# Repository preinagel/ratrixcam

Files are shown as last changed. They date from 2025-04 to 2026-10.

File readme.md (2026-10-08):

## Overview
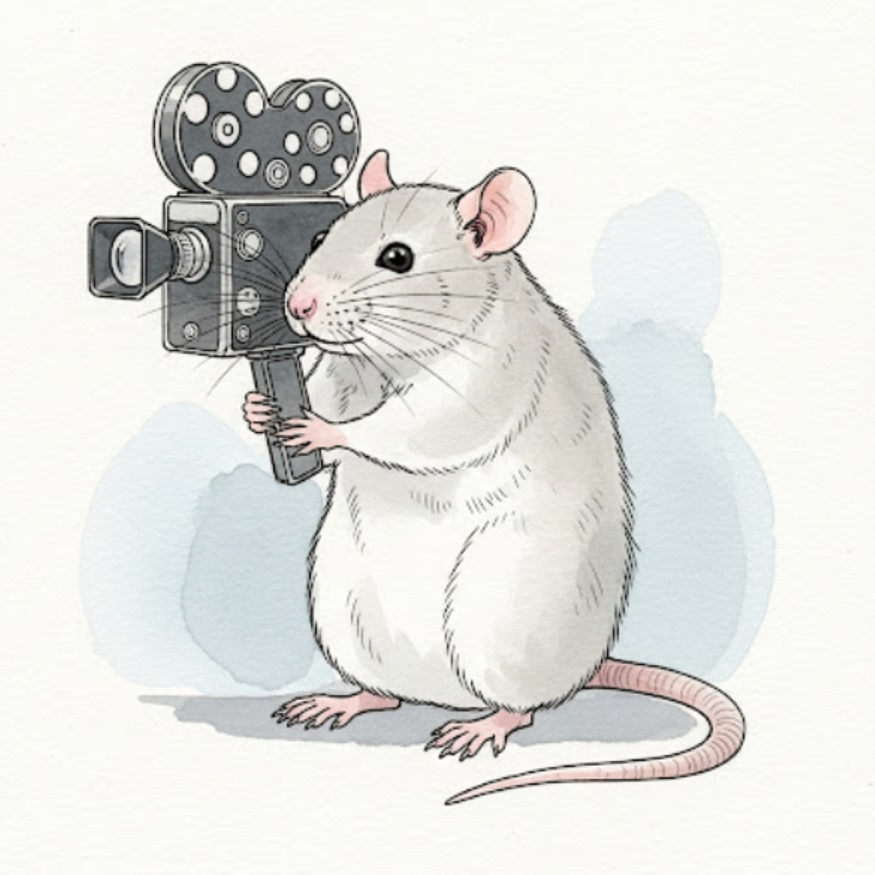
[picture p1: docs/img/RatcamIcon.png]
 The ratrixCam system is an inexpensive, bare-bones open-source hardware and software package designed to record video 24 hours a day 7 days a week for at least 1 week continuously, with the minimum possible frame drops within videos or gaps between videos. It was developed for in-home-cage animal behavior monitoring, but could be used in any application requiring continuous uninterrupted video recording. The code provides a minimal graphical user interface that allows the user to monitor the camera status and session statistics during the run. The code is currently verified to support up to 8 cameras streaming at 30fps, 640x480p. 

See the [Camera User Manual](./docs/CameraUserManual.md), the [VideoProc User Manual](./docs/VideoProcUserManual.md) and [Setup Instructions](./docs/SetUpInstructions.md) for more information.

Project started by Blake Bruell and Pamela Reinagel 2025

With support from the [NIH BRAIN Initiative](https://braininitiative.nih.gov/) and [NINDS](https://www.ninds.nih.gov/) 1R34NS132037-01

## Running the tests

The `videoproc` tools (`compress_drive.py`, `confirm_and_delete.py`) have a pytest suite
under `tests/`. It generates its own synthetic video clips and runs entirely in temporary
directories -- no real recordings or network drives are touched.

Requirements: Python 3.10+, `ffmpeg` on PATH, and the packages `videoproc` itself already
needs (`opencv-python`, `numpy`), plus `pytest`:

    pip install -r requirements-dev.txt

Run the suite from the repository root:

    pytest -v

GitHub Actions runs the same suite on every push and pull request to `dev` and `main`
(see `.github/workflows/tests.yml`).

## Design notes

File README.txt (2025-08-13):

ratrixCam 0.0

The ratrixCam system is an inexpensive, bare-bones open-source hardware and software package designed to record video 24 hours a day 7 days a week for at least 1 week continuously, with the minimum possible frame drops within videos or gaps between videos. It is currently verified to support up to 8 cameras streaming at 30fps, 640x480p. It relies on MacMini hardware, ArduCam USB cameras, high-end USB Hubs, and high-speed, high-capacity external SSD drives. The code provides a minimal graphical user interface that allows the user to monitor the camera status and session statistics continuously during the run.

Project started by Blake Bruell and Pamela Reinagel 2025

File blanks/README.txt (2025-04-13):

Blank images to display when camera is offline

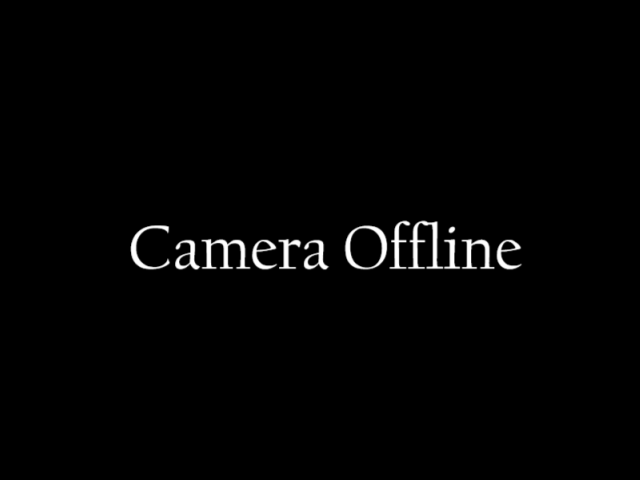
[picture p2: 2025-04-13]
blanks/offline_status.png

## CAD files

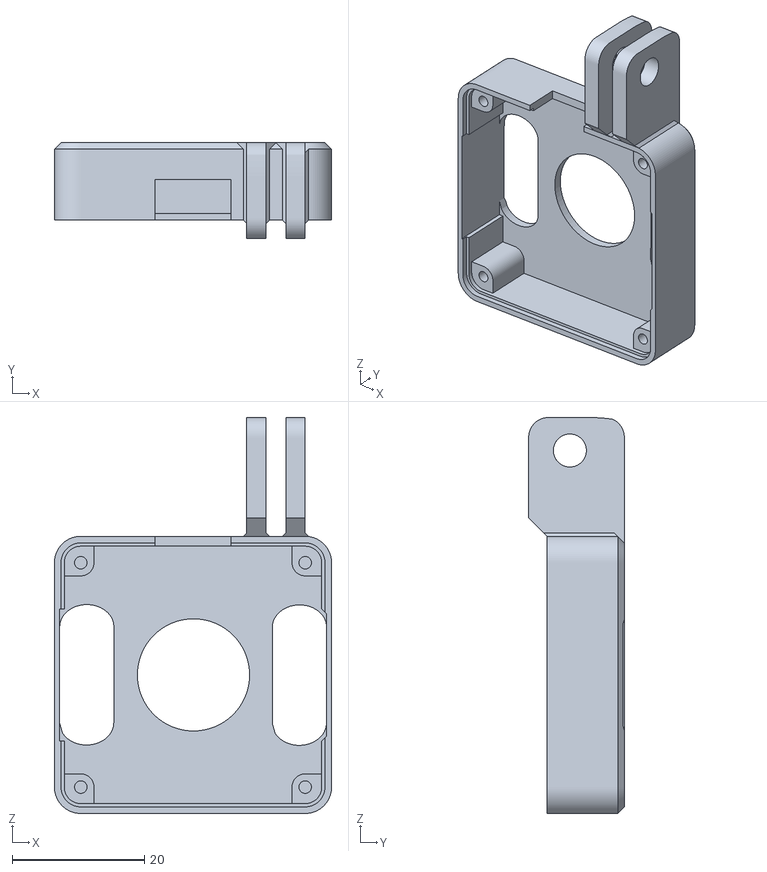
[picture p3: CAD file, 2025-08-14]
docs/ratrixCamCameraCaseFront.stl
42.0 x 14.5 x 60.0

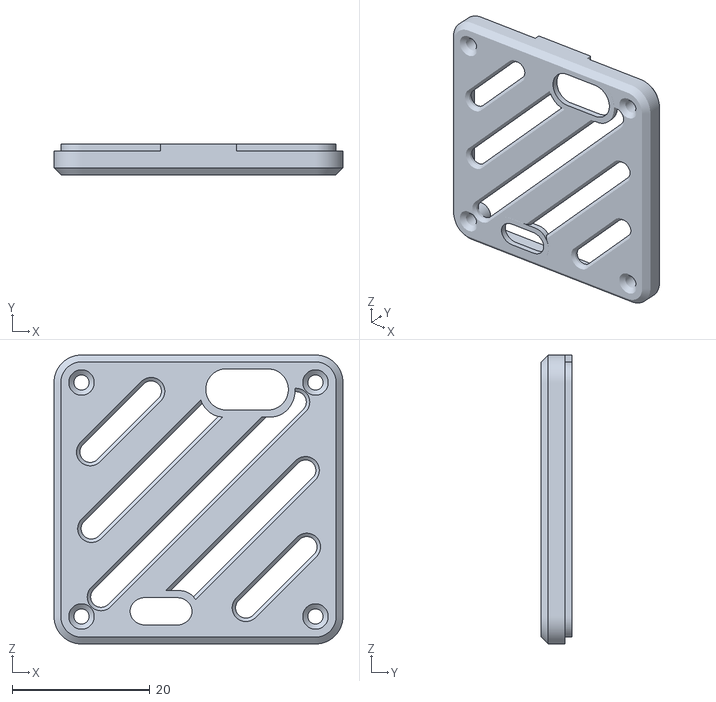
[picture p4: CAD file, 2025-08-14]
docs/ratrixCamCameraCaseBack.stl
42.0 x 4.54 x 42.0

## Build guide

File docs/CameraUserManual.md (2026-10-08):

## Overview
 The ratrixCam system is an inexpensive, bare-bones open-source hardware and software package designed to record video 24 hours a day 7 days a week for at least 1 week continuously, with the minimum possible frame drops within videos or gaps between videos. It was developed for in-home-cage animal behavior monitoring, but could be used in any application requiring continuous uninterrupted video recording. The code provides a minimal graphical user interface that allows the user to monitor the camera status and session statistics during the run. The code is currently verified to support up to 8 cameras streaming at 30fps, 640x480p. 

### System Operation in Brief
- Attach an empty SSD drive
- Launch software
- Click "Start Recording" 
  (Camera images will be displayed while recording) 
- Every week or so:
  - Click "Stop Recording"
  - Swap out full SSD drive for empty one
  - Click "Start recording"
  - Transfer videos off the full SSD drive

## Operation Instructions in Detail
Double click on `cam_start.scpt` to open it, and click ‘play’ to launch ratrixCam. (Alternatively, the command found within that script can be typed directly into a terminal window).

First the Configuration Editor will open, displaying the name of the study and a description of each camera view, which are loaded from the `config.json` file. The labels are arranged on the screen in the position corresponding to where the camera views will appear in the video acquisition monitor. If you want to change the labels, we will discuss editing them later.

When you click Start Recording, the configuration editor closes and a Monitor Window opens to monitor video acquisition status. By default, the cameras 1-8 appear in the following layout, which reflects the use case where the cameras are used to monitor two adjacent cages or rigs, four cameras per animal.

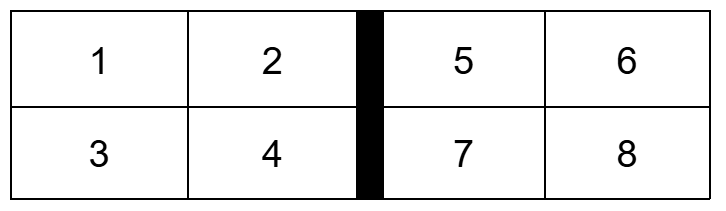
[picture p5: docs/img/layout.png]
layout diagram
 

As each camera connects, its current view will start to update in the display; it should take 15-60 seconds for all 8 cameras to start. Note that all cameras must be present before the cameras will launch. By default, videos are recorded at 30fps but the displayed images update once per second.  To the right of the camera views, there are text fields indicating basic session information. You may have to resize the window to see everything. 

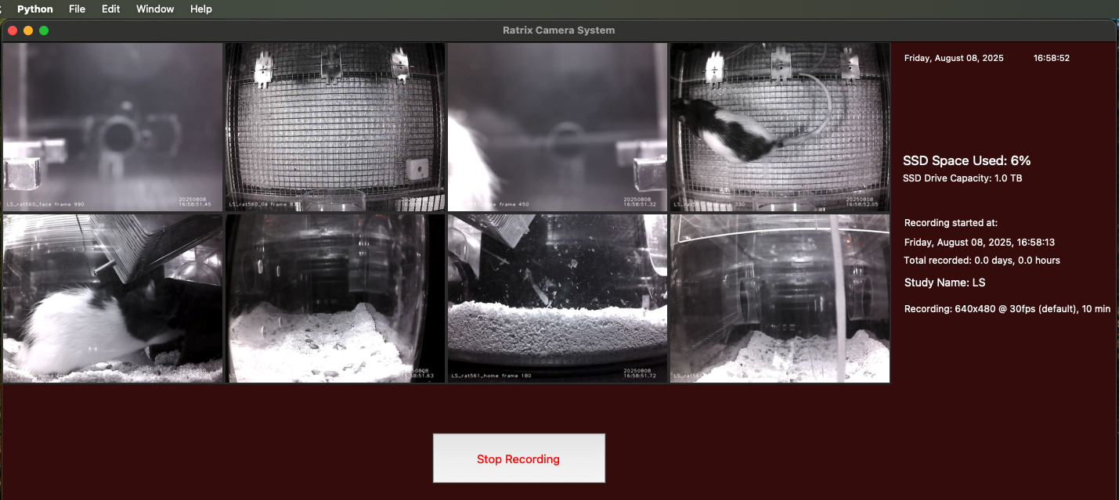
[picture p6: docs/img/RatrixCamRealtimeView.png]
  
  
While the cameras are starting up, locate the Terminal Window and move it to where you will be able to watch the messages that scroll by. If there are warnings or errors they will appear here.

#### Changing the labels
The “study name” is appended to the start of every filename and overlaid on every video frame; it should be a short string identifying the overall study. The “camera names” are also included in video filenames and overlaid on every frame; these should be short descriptions of the distinct fields of view. The labels are meant to be fixed for the duration of a study. Timestamps will be added to filenames and overlaid on video frames to distinguish individual runs and slices. Whenever you start a recording session you can verify that overlaid labels and camera views match. Cameras should always appear in the same positions, as long as they remain plugged into the same USB hub ports.
When setting up a new study, launch the cameras and verify which camera’s field of view appears at each position on the display. Then stop the run, relaunch ratrixcam, and edit the labels in the Configuration Editor to reflect this information. You must click “save changes” for changes to take effect. This action also updates your `config.json` file, so the new labels will repopulate automatically in future runs.  Alternatively, you can edit these within the `config.json` file directly in any text editor. The study name is set by the "study_label" property, and the camera names are set by the “name” property of each camera within "cameras". 

### What happens during a run

Once the cameras have been launched, the system can record continuously indefinitely, until the storage media is full. During the run, the Monitor Window will update each camera’s view once per second, as well as displaying textual status information. Each video stream will be saved as many separate, short video files (“slices”), whose duration is specified in the `config.json` file. We recommend using 600s (10 min) slices for data acquisition. 

We designed and tested the system for week-long continuous recording sessions from 8 cameras recording at 640x480 resolution at 30fps, for which a 4TB external SSD drive was sufficient to hold one week of video output. In our conditions a MacMini2 could run at least two of the 8 cameras at 780p resolution stably (accumulating data at 1.5x the rate).

To end a recording session, click the Stop Recording button. Watch the Terminal Window for messages as a graceful shutdown and cleanup is performed. When the terminal indicates shutdown is complete, you can export its contents to a text file to retain a detailed log of events and errors during the session. You can then swap the filled external drive for an empty one and start a new run. The gap in recording time can be as short as one minute. 

### Failure recovery

It should be exceedingly rare for cameras to drop out during a run. Nevertheless, if a camera should drop out during a run, the system will continue to function as well as possible. The Monitor Window will indicate that the camera is offline, save the partial video file, and then continually attempt to restart the camera. There will be a gap in the video record for the camera that went down until it restarts, but others will not be affected. All these events are logged in the Terminal Window. If more than one camera goes down at the same time, the system will wait until all cameras are detected again before any of them attempt to restart. This prevents them from starting up and stealing another camera's ID slot.

If the output drive fills up during a session, the software will continue to re-try saving the files until the session is ended. For this reason, if you hot-swap a new drive without stopping the software, all the untransferred files should then be saved normally. However, if both the external output drive and internal hard drive fill up during a run, all video from that time on will be lost. Therefore, we recommend keeping at least 1TB free on the Mac’s internal hard disk.

Temporary video files accumulate in the temporary folder on the hard drive until they are transferred to the output drive. When you stop recording, the shutdown sequence will continue attempting to write the unsaved files, but if this fails enough times it will eventually give up and kill any unsuccessful file transfer requests. The Terminal Window will show error messages for failed file transfers. In this case, any un-transferred video files can be manually rescued from the temporary folder. 

If the program hangs (Stop Recording button is not responding) you can close the terminal window to stop the run. You can then manually copy the un-transferred files from the temporary folder.

Except when the external drive is full, hot swapping of the external drive during a run is not recommended. However, it would in fact probably be fine. If you unplug media in the middle of writing a file to the external drive, it will still most likely recover gracefully and re-attempt to transfer the file to the new drive when it connects. Nevertheless, we provide no guarantees.

### Settings in the config file
#### Number of Cameras 
The code will only start recording after it detects (at least) the expected number of cameras. The default configuration file presumes 8 cameras. Therefore, if you want to run the system with fewer than 8 cameras, you must edit the config file. Each camera is defined by a block such as:
`
{
      "name": "cam1",
      "row": 1,
      "col": 1
    }
`

Note that the cameras will be launched in the order listed, but you can include whichever subset you want. For example, if camera #7 is temporarily broken you can delete the cam7 block, and the other cameras will retain their usual names and display positions. But the computer must detect (at least) as many connected cameras as you have entries in the config file before the cameras will launch.  If more are connected, it will use the first N it sees.

The code supports recording of up to eight cameras, and will behave strangely if you define more than eight. 

#### Settings shared by all cameras in a given run 
| Setting | Description |
| --- | --- |
| save_path | folder where output videos will be saved |
| temp_path | folder where temporary video files will be staged |
| blank_image | image file to display when a camera is offline |
| stills_path | folder where the most recent displayed frame is kept |
| rack_name | string uniquely identifying the recording system instance  |
| study_label | string identifying the study or experiment (used in labels and filenames) |
| time_slice | duration in seconds of each video file |
*Advanced settings*
| default_fps     | frames per second, if not otherwise specified |
| default_width   | frame width in pixels, if not otherwise specified |
| default_height  | frame height in pixels, if not otherwise specified |
| default_cam_exposure   | duration the "shutter" is open, if not otherwise specified  |
| preview_interval       | interval in seconds between updates of displayed image |
| codec                  | video codec |
| video_ext              | video file extension |
 
#### Settings for individual cameras 
| Setting | Description |
| --- | --- |
| name | string associated with the camera (used in labels, filenames) |
| row | row in display where camera image is shown (valid values 1 or 2) |
| col |  column in display where camera image is shown (valid values 1,2,4,5) |
*Overriding defaults*
| fps        |  frame rate  |
| width      |  frame width in pixels |
| height     |  frame height in pixels |
| exposure   |  duration the "shutter" is open each frame  |

There is little to no error checking on these settings. The user is responsible for not assigning two camera images to the same display location, only selecting camera settings that are supported by the camera they are using, and so forth.

*Unsupported options*
The following config settings are obligatory because these functionalities are not yet implemented
`  "recording_audio": false,
  "recording_ttl": false
 ` 

## Technical Details
Information below here is not necessary to use the system, but may be useful to users who have exacting technical requirements, for debugging system failures, or for developers wanting to modify the code.

### Temporary and final files

The videos are initially streamed to temporary files in the temporary directory specified in the config file. This directory should be on the internal hard drive of the mac; we recommend a folder on the desktop. The internal HD is used because the transfer speed or write speed of an external drive might not be able to keep up with all 8 cameras in real time.  

When a time slice ends, this temporary file is closed, and a separate parallel process is launched to transfer it to the output drive (typically an external hard drive, to allow for media swapping).  When the file has been confirmed to be successfully transferred, the temporary file is deleted from the hard drive. Therefore the hard drive does not need to have enough capacity for the entire recording session’s videos.  

The temporary folder should be empty of video files when the session ends. However, if any videos failed to transfer for any reason, such as the output drive being full, the temporary files will stay in the temporary folder. Our routine workflow is to manually move the temporary folder onto the portable drive just before ejecting it from the Mac. If the temporary folder is empty as expected, this action takes no time and cleans up the desktop; but if any files were not transferred, they will be transferred at that time.

### Video transfer and processing steps

The cameras have on-board hardware to compress individual video frames to mjpegs as they are captured. These frames are written directly to the temporary video files. This makes it possible to keep up with the bandwidth of 8 cameras in real time. After a video file is closed, we launch a separate process to transfer the file to the output drive. The ratrixcam code is smart about monitoring these processes and cleaning up after them, so we should not leave behind orphan processes.

However, within-frame compression is very inefficient, so the video files are large. Therefore, after a recording session ends, we recommend further compression before archiving. This places high demands on the CPU and RAM, and can take more time to compress a video than the duration of the video. Therefore it can’t be run on the Mac during recording. 

On a separate machine dedicated to this purpose, we compress videos with an inter-frame compression algorithm that achieves much higher compression without noticeable loss of quality (“visually lossless”). This algorithm is computationally intensive and not supported by the Mac’s dedicated video processor. First we run a lightweight motion detection algorithm to identify whether a video contains significant motion. Videos without motion can be compressed at very high compression ratios. The compression and verification tools are included in this repository under `videoproc/`; see the [VideoProc User Manual](./VideoProcUserManual.md).

#### Transcoding on the fly
We did implement code for compressing the videos on the fly using ffmpeg but this feature is currently disabled. To avoid interfering with acquisition we used the Mac’s dedicated hardware for video processing, instead of the Mac’s CPU. This is fast and does not interfere with ongoing video acquisition, but it does not compress the files very efficiently, and introduces timing instability we didn’t find worth solving. If you want to try getting it working on your setup, look in the file `ratrix_cam_server.py` for the disabled code.

### Timing Issues

There should not be any dropped frames within videos or unrecorded gaps between video files; this was a primary functional specification for developing this system. However, the timestamps on video frames are only approximate. The timestamps indicate when the frame was read from the buffer, which is usually but not always within 1-2ms of when it was written to the buffer by the camera. The frame number overlaid on each frame is the definitive indicator of the passage of time since a video stream opened. 

The cameras we are using run at only approximately the advertised frame rate. The breaks between video slices are determined by the system clock, not the number of frames.  Therefore if you specify 30fps and 600s slices, you may not get exactly 18,000 frames per video. But you should get close to the same number of frames in each video, and this should be very close to 10 minutes in duration. However, video players and file systems will indicate the “duration” of the video by dividing the number of frames by the nominal (specified) frame rate, making it appear that the video was cut short, even though it was not.

For example, if the true frame rate of a camera is 29fps, your 600s videos will have 29*600=17,400 frames +/-1, and your video player or file system will probably tell you the video is 17,400/30 = 580s in duration. If you want to verify there is no gap between videos, check the frame numbers. A single dropped frame causes the camera to shut down and re-launch. All such events are logged in the Terminal Window. Frame numbers restart at 0 every time a camera is launched or re-launched. 

Timestamp inaccuracies (i.e. uneven delays in capturing frames from the buffers) are common in the first few minutes of a session due to the high load on system resources during startup, and can occur any time the Mac’s resources are stressed. Although the video is actually fine, with no missing frames, the overlaid times may be off. To minimize this, avoid using any other USB-connected devices on the Mac (use a bluetooth mouse and keyboard); avoid running any other programs on the Mac during recording; disable automatic updates, do not install security software, keep the Mac in airplane mode by default. You can connect to the network through a secure internal network server when it is necessary to go online.

### Capacity limitations
The graphical interface presumes a maximum of 8 cameras; that code would need to be generalized to support any more than this number. However, the code for recording the videos itself has no upper limit on the number of cameras it will attempt to record simultaneously. At some point the hardware would not be able to keep up with the data stream; we have not tested this practical limit.

The limits on the maximum number of cameras and maximum resolution of cameras could probably be improved further if you are willing to dig into the code. We had to add timeouts and/or multiple retries in several places to prevent failures due to race conditions. We didn’t solve this in a general way, we just found values that are sufficient for the system to be reliable within the advertised specifications.

So if you want to try pushing the system beyond those specs, go ahead and try. You will know you’re in trouble when you start getting copious error messages in the terminal, including cameras frequently failing to capture a frame and shutting down, or files repeatedly failing to write and the GUI becoming non-responsive. You can attempt to remedy this by increasing the wait times or number of retries within the Python code.

The capacity of the USB bus could be a hard limiting factor, but this is probably not the constraint currently.

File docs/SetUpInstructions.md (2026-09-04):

# Setting up a RatrixCam System
Instructions for setting up an 8-camera instance for deployment in an animal housing environment.[^1]

## Parts List
# Electronics
 
- Mac Mini (M2 or higher), with power cord
- Audio cable 
- Bluetooth Keyboard/Mouse
- Portable LCD display, 10.5”, HDMI cable, USB-C to USB-A power cable
- 2 powered Rosonway USB hubs with 4+ USB-A ports (3.0 or higher) → Thunderbolt 3 USB-C
- 2 4TB SSD external drives for fast USB-C or thunderbolt 
- 1 fast USB-C or thunderbolt cable for SSD (or USB-C to USB-A for older macs)
- 8 Arducam USB cameras that support IR-only image capture (model B0506 1080P)
- 3 IR illuminators; mounting hardware if needed 
- 1 grounded plug strip with at least 8 outlets, widely spaced to allow for cubes

# Optics/Cameras
- Wide-angle lenses M12 mount where needed (e.g. home cage)
- Close-up lenses M12 mount where needed (e.g. face view) 
- 8 IR-pass filters (IR-pass acrylic sheet, cut into ~2” squares)
- Adhesive polarizing film sufficient to cover the 8 IR-pass filters
- 8 camera cases with GoPro mount (3-D printed)  [front](./ratrixCamCameraCaseFront.stl) and [back](./ratrixCamCameraCaseBack.stl)
- small self-tapping screws for camera cases
- 8 light-blocking camera hoods (plastic or 3-D printed)
- Some mechanism to lightly mount hood to camera case (e.g. magnets, velcro…)
- Some mechanism to hold an IR-pass filter in front of camera (e.g., slots in hood)
- 8 3-inch metal gopro arms; additional arms as needed for configuration
- 8 flat-mount adhesive GoPro quick-release helmet mounts
- Extra gopro screws, acorn nuts
- Wrenches and pliers for mounting and tightening go pro mounts 
- Assorted zip ties for cable routing

## Step 1. Pre-assemble 8 cameras
1. Disable the IR cut filters  (for model B0506 Arducam) [^2]
   - Plug camera into any computer and view image in any software
   - Turn off lights/cover the light sensor until you hear IR cut filter retract
   - Verify that image is good in dark under IR illumination through an IR pass filter
   - Unplug camera before turning on lights (to keep filter retracted)
   - Remove photo sensor and unplug the IR-filter-motor cable from camera card
2. Use pliers to gently loosen the focus lock ring, so lens can be focused manually
3. Remove the illuminating LEDs for any camera that would otherwise cause reflected glare 
4. Put each camera in a 3D-printed camera case with openings for cooling
6. Secure case closed with 2-4 tiny self-tapping screws
7. Swap in alternative lenses if applicable
8. Mount the camera case to a go-pro extender arm.
   - Large thumb-screw GoPro screws are easier to work with in the dark, but think about which way you want them to protrude
   - Zip tie the camera cable to the closest GoPro arm such that tension on the cable will not unplug or stress the connector at the camera board
9. Connect the other end of the GoPro arm to a GoPro quick-disconnect connector, snapped into a flat adhesive-mount quick-disconnect base.
10. Put polarizing film on acrylic IR-pass filter, mount filter on hood, put hood on camera using magnets.
11. Use a silver sharpie to label camera case, USB-A end of its cable, and outside of hood

## Step 2. Prepare the Mac 
Note: these instructions assume the user is completely unfamiliar with Python and not a programmer, and therefore includes basic setup instructions for the Python environment that Python users can safely ignore.

1. Set up a Mac Mini with desired user name and password
2. Connect to a network
3. Download these programs from the internet and install:
- Visual Studio (from https://visualstudio.microsoft.com/downloads/)
- Python (from https://www.python.org/downloads/)
- GitHub desktop  (from https://desktop.github.com/download/)
4. Launch GitHub Desktop app and log in  
5. Use the clone repository menu option to clone preinagel/ratrixcam to the desktop.  
6. Give the terminal Full Disk Access permission:
    - In System Settings - Privacy & Security - Full Disk Access, click add (+)
    - Provide password when prompted, select Terminal from the applications list and ‘open’
7. Open a Terminal window and type the following commands (expect some text to scroll by indicating successful installation of each item. If you get error messages read them.)
```
> pip3 install –upgrade pip
> pip3 install basedpyright
> pip3 install pydantic
> pip3 install pillow
> pip3 install opencv-python
> python3
```
(that should launch python within the terminal; then type:)
```
    >>> import cv2
    >>> cv2.version
```
(if a version number is displayed, you’re good)

8. Close the terminal window, turn wireless off or put in Airplane Mode
9. Label computer box with name and MAC address.
10. Connect any USB drive, set its name to ‘data’ (to test video output)
11. Connect the powered USB hubs into thunderbolt ports (left hub in left port, right hub in next one), connect the hubs to power sources, and power on only the ports you plan to use
12. Connect any USB camera to each of the 4 ports on each hub
13. Open the ratrixcam folder, and copy config.json and  cam_start.scpt to the desktop (rename if desired)
14. Click the script to open it and edit the paths
  - path includes the username you are logged in as, on the mac
  - change “config.json” to the path and name of your renamed config file
  - change the path and name of the output drive if necessary
  - click the hammer icon to save changes.

15. Run script to try launching the camera code. If this fails, check terminal window for errors.
16. Click Start Recording, wait until all 8 cameras show up. The camera numbers are associated with positions on the screen as follows:
    
     layout diagram
   - Label the USB ports on the hubs according to their camera numbers 1 through 8
   - Label the thunderbolt ports on the Mac to reflect which port serves 1-4 vs. 5-8
   - Label the Mac-end of the USB hub cable with this information as well
     
17. Check if videos appear in the specified temp folder

18. To the right of the camera view images the GUI displays text with session information. Stretch window if needed to see this. One fact displayed is the duration of individual video files that will be saved. 

19. Allow cameras to run for at least this duration, then check if videos get transferred to the output drive when the file closes.

20. Re-launch once more to confirm everything comes up in the right place again.

### Notes on how cameras are linked to IDs during setup
When a new system is assembled you need to determine which USB port corresponds to which video stream. If you do not change the hardware setup (don’t move USB hubs to different ports, don’t change USB hubs or which USB ports on hubs are used, don’t plug cameras into any other port) the order should be stable. This isn’t formally guaranteed by macOS, but seems to be reliable.

You can edit your custom config.json file in any text editor if you need to enter custom camera settings (frame rate, resolution, exposure time, GUI display position, enable/disable specific cameras).

The cameras will not launch until all the expected cameras are detected. This ensures they are assigned the correct video stream IDs. Therefore if you want to run this program with fewer than 8 cameras, you’ll need to edit LocalConfig.json to indicate how many cameras to expect and which camera streams (ports) will have cameras installed. 

Once the cameras launch, for the duration of that session you should be able to unplug any camera without the other cameras changing their identities. If you plug the camera back in again it should resume with the correct identity. However if more than one camera has been unplugged, all of them have to be plugged in again before any of them will re-launch. This protects against cameras switching identities if they are re-connected in the wrong order.

# Connecting in deployment location
Once cameras are prepared and Mac is set up, you can bring to the location you want to deploy for final setup. (The intended use of the system is in-cage monitoring of animals, which is typically in a less convenient environment).

1. Plug in the mac, attach the mini monitor and mount where it will be convenient
2. Plug Audio cable into mac, connect other end to any grounded device (e.g. a monitor). 
  *if you do not do this, the Mac will be ungrounded, as well as the cameras!*
3. Connect the external data drive
    - Mount one end of a high speed data cable somewhere accessible 
    - Plug one 4TB SSD drive into the cable
    - Plug the other end of the cable into the mac. Use a thunderbolt port if available, otherwise a USB-C port, otherwise a USB-A port.
      *we do not recommend using the USB hub that serves the cameras, even if it has open ports*
4. Mount IR lamps so that they illuminate what you want to capture in the videos. Adjustable mounts are best.
5. Mount USB hubs near where cameras will be deployed
   - route hub power cables to plug strip & secure with zip ties
   - plug into the thunderbolt ports of the mac as labeled during pre-setup
   - if an extender cable is needed, use a high speed/thunderbolt rated cable
   - faulty extension cables are a common cause of system instability or failure
6. Plug cameras into the hub ports in the positions previously labeled
7. Turn on USB ports you will use for the cameras, turn off the others (using local power buttons)
8. Turn on the mac and launch the camera code
9. Start recording and verify the camera views appear at the desired positions and have correct labels. If not, follow instructions above to rearrange until correct.
10. Finalize camera positions and focus them
    - position the camera so the field of view is as desired
    - mark the position of the GoPro mount base with a sharpie, then stick the adhesive base on
    - mount the camera on the GoPro bracket
    - fine-adjust the position and arm angles to get desired FOV, and tighten screws with wrenches to fix the camera position
    - Manually focus on an object at the distance you intend to video record; hand-tighten the focus lock ring
11. Put light blocking hood with IR-pass filter on, confirm image is good in the dark
12. Secure all cables with zip ties to absolutely minimize loose wires.

At this point the camera assignments should be stable.  

### Before the first run
The code comes with an Apple script `cam_start.scpt` and a configuration file `config.json` (both of which we recommend you move out of the ratrixcam folder and keep on the Mac’s desktop). You may rename these to anything you wish. 

Open `cam_start.scpt` in the Apple Script Editor by double clicking on its icon.  Edit the first path in the script to reflect where the ratrixcam folder has been installed on your computer. Edit the second path in the script to reflect the full path to the configuration file. Click the hammer icon to save your changes. You will not have to do these steps again unless you change paths or configuration files. 

Open the file `config.json` in a Python editor or any text editor, and edit the paths to indicate where various temporary and permanent data files should go. The setting:
`"save_path": "/Volumes/data/" `
determines where video output is saved. If you want to save to an external SSD drive and you name your SSD drive ‘data’, you can leave the default path as is. If you want to save files somewhere else, edit this setting. Note that the cameras won’t start if the specified path does not exist. The remaining paths are for temporary files, which we recommend putting on the desktop. If ratrixcam is installed on the desktop you only need to change “username” to the username you are logged in under on the Mac
```
  "temp_path": "/Users/username/Desktop/temp_videos/"
  "blank_image":"/Users/username/Desktop/ratrixcam/blanks/offline_status.png"
  "stills_path": "/Users/username/Desktop/temp_videos/status/" 
```
If you will be running the system with 8 cameras, these are the only things that must be edited for the code to run. If you have fewer than 8 cameras, you’ll need to reduce the number of cameras defined in the `config.json` file.

The descriptive strings for the study name and camera views can be edited in the config file, but you’ll also be able to do this in the configuration editor when you run the program (see User Manual). 

### Notes on USB hub choice
It may not be obvious, but the specific USB hub brand is critical.  We use Rosonway. Most USB splitters and many powered USB hubs do not work, even if they are rated for sufficient speed. Other hubs may work, but would require testing. The reason for this, briefly, is that Macs do not support direct addressing of video devices or USB ports. Therefore, to make sure the cameras are reliably assigned to the same identity within the ratrixcam code, we are depending on the obscure fact that when the Mac looks for video streams, it polls its thunderbolt ports in a consistent order; and some but not all USB hubs reliably poll their ports in a specific order. Because we depend on this to define camera identities, ratrixCam will not start until the Mac reports that it sees the expected number of video streams.

### Notes on camera choice
The model B0506 Arducam is currently (6/2025) the only comparable USB camera we could find that has good IR-sensitive recording. (We tested a large number of other supposedly IR-sensitive cameras, but the image through a true IR-pass filter was extremely poor, even with high IR illumination). This camera has manual focus, is a plus in our application. Word of warning: some secondary vendors ship this camera in a case, but we found that these often have glued the lens in place such that it can neither be focused nor removed. We would have preferred a camera without photo-sensor controlled IR-cut technology (which we had to disable) and that runs at 60fps.  Having 24 bit color is useless, as IR images are monochrome, making files unnecessarily large. Transcoding to monochrome doesn’t seem to be widely supported.  

This camera is limited to 30fps; streaming 1080P at 24bit color mjpeg it has a raw uncompressed bit rate of ~1.5Gbps, far below the 5Gbps capacity of the USB channel. However, we use them at lower resolution to avoid overwhelming the computer when streaming 8 cameras at once. Using 640x480 is sufficient for applications like DeepLabCut and SLEAP, and keeps the file sizes smaller so the system can be run for longer sessions before running out of space on the drive.  

### Notes on lenses
The lenses that ship with model B0506 Arducam are fine, but it's useful that the lens is easily removable so custom optics can be swapped in when needed. Wide angle or fisheye lenses are widely available in the consumer market. Close-up lenses meeting particular specifications were more difficult to find. For example, we wanted a close up of a rodent's face at a fixed location (behavioral lick port) from a distance of 17cm; nothing on the consumer market worked well. We are using Edmund Optics 12mm UCi Series Lens, f/2.8. We can recommend Edmund Optics for a wide selection of scientific lenses and excellent technical sales support.

### Notes on mounting hardware
We found the GoPro standard useful because there is a wide array of available mounting hardware options, which are already optimized to be lightweight, low profile, impervious to vibration and moisture. Once mounting screws are tightened, we find GoPro mounts to hold camera positions very securely and stably compared to clip-on, tripod, or bendable camera mounts. 

We 3D printed custom GoPro mount camera cases. Here are the stl files for the [front](./ratrixCamCameraCaseFront.stl) and [back](./ratrixCamCameraCaseBack.stl). We derived these from files that were provided under CC BY-NC 4.0 license [here](https://www.printables.com/model/661757-arducam-b0205-ir-case-gopro-mount/files). Specifically, we modified the depth of the box and the positions and sizes of openings for connectors and LEDs to accomodate differences in the camera card layout; and removed the photosensor opening. We printed these in PLA, high res, dense infill.

## For additional operating instructions see the User Manual

[^1]:We have developed and tested this code on specific hardware. Some details relevant to achieving robust performance were hardware-specific.  In principle this code could work on any operating system, computer platform, or USB camera type, but in practice any of these generalizations will require additional testing and likely tweaking.

This system was designed for monitoring animal behavior in a home-cage environment, with minimal disturbance of the animals. For this reason, we use low-wavelength IR illumination, IR-sensitive cameras, and IR-pass filters. This ensures the cameras do not disturb the animal sleep cycle, and the video images are consistent regardless of whether room lights are on or off.  We also use our own IR lamps and remove the built-in IR LEDs on the cameras, because in our experience it was not possible to position the LEDs to prevent reflection glare and hotspots.  If these constraints are not relevant to your application, instructions related to those features can be ignored.

[^2]: The IR cut filter exists to *exclude* IR light from reaching the camera sensor when there is sufficient visible spectrum light, because images with visible light only are crisper, which is what consumers usually prefer. However, in our application we plan to use an IR-pass filter that *excludes visible light*, so that the images of animals will be invariant to ambient illumination. Therefore we want to admit IR light to the camera, even when the room is bright. The IR cut filter itself could not be readily removed from the camera. Our choice was to put IR cut filter in the retracted (night vision) position and then remove the sensor. One could also optically block the photosensor that detects ambient light.

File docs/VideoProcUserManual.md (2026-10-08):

## Overview
videoproc is the companion to ratrixCam for what happens *after* a recording session: compressing the week's videos down to an archivable size, verifying that every compressed copy is sound, and only then deleting the bulky originals. It consists of two command-line tools in the `videoproc/` folder of this repository:

- `compress_drive.py` compresses every video in a source folder into a standard archive layout, optionally choosing how hard to compress each clip from a quick motion analysis, and verifies each output as it goes.
- `confirm_and_delete.py` re-checks, file by file, that a valid compressed copy exists at the archive for every original, and deletes the originals only when asked, only after showing you the tally, and only after you type `DELETE`.

Compression is CPU-intensive — it can take longer than the video's own duration — so it is not run on the recording Mac during a session. We run it on a separate computer against folders copied off the recording drives. Both tools write a complete record of what they did, so you can later reconstruct how any archived clip was produced.

### System Operation in Brief
- Run `compress_drive.py` on a session folder; it works unattended for hours.
- Read the summary it prints at the end: every file should be `compressed`, `copied`, or `already_done`, and nothing flagged for review.
- Run `confirm_and_delete.py --delete` on the same folder; it checks every file, decodes every archived copy, prints a summary, and asks you to type `DELETE`.
- Compare the summary with what you expected before typing `DELETE`.
- Deal with whatever is left in the source folder (notes, listings, broken clips); the tool leaves those for you.

## Operation Instructions in Detail

### Preparing
Both tools are run from a terminal, from the `videoproc/` folder of your clone of this repository. They need `ffmpeg` on the PATH and Python 3 with `opencv-python` and `numpy`. The source folder and the destination (archive) folder must both exist. If your archive contains files named by an older convention, see *Legacy filenames* under Technical Details before you start.

Every command begins by asking you to press Enter after it prints its configuration, so you can catch a wrong path or flag before anything happens.

### Compressing a session folder
A typical command looks like

```
cd <path-to-clone>/videoproc
python3 -u compress_drive.py <source folder> <archive root> --output_studyname <NAME> --pattern '<glob>' --motion_detection --motion_threshold 0.001
```

`<source folder>` is searched with `--pattern` (a glob relative to the source; the default `**/LS*/*.mp4` finds `.mp4` files inside folders whose names start with `LS`). Every clip found gets a destination path built from its own filename:

```
<archive root>/<subjectID>/<NAME>_<subjectID>_<view>_<YYYYMMDD>/<subjectID>_<view>_<YYYYMMDD>_<HH-MM-SS>.mp4
```

so the archive is organized by subject, then by subject-view-day, regardless of how the source folders were arranged.

As it runs, the terminal shows one block per clip: the filename, whether motion was found (if motion detection is on), which compression setting was chosen, and any problem. On an 8-core Apple-silicon Mac a 10-minute 640×480 clip takes roughly 15–25 seconds, i.e. 150–250 clips per hour. If the source or archive is on a network volume that drops out, the tool pauses and retries for up to ten hours before giving up.

At the end it prints a summary: how many files matched the pattern, how many rows were logged (these should be equal), a count per outcome, whether motion detection was on, and how many rows were flagged for human review, with the path of the file listing them. Files that were already correctly archived are reported as `already_done` and not touched, so re-running a folder is cheap and safe.

What the tool will **not** do: it never deletes or modifies anything in the source folder; it never copies a file it cannot open; and it never silently overwrites a different video that happens to sit at the destination path — such collisions are flagged for you.

### Verifying and deleting the originals
When a folder has been compressed and the archive has been backed up, run

```
cd <path-to-clone>/videoproc
python3 -u confirm_and_delete.py <source folder> <archive root> --output_studyname <NAME> --pattern '<glob>' --delete
```

The tool works in two passes. First the cheap checks on every file: the filename parses, a copy exists at the destination, it opens, it is compressed (not raw), its frame count equals the original's, and it is at least `--min_age_hours` old (default 24 hours, so that a nightly backup has had time to run). If anything fails these checks and you did not pass `--delete_partial`, the run stops right there with `REFUSING to delete` and tells you why, before spending time on the second pass. Otherwise every surviving candidate is fully decoded with ffmpeg (about 1–3 seconds per clip) to catch corruption that a frame count cannot. Then the summary is printed and you are asked to type `DELETE`. Anything else aborts with nothing deleted.

Deletion removes the verified originals one at a time, recording each in `deletion_log.csv`. Folders left empty are removed; folders that still contain something — notes, listings, a clip that could not be verified — are kept and their contents listed, so what remains is exactly what needs a human decision.

To see what the tool would decide without deleting anything, run the same command without `--delete` (add `--decode` to include the decode pass).

### Working with several computers
Several compressions may run at once against the same archive, from one or several computers, as long as each works on a different source folder; the shared run index is locked against simultaneous writes. Never run two jobs over the same source folder at the same time. A single computer is CPU-bound by one compression; a verification can overlap with it.

## Settings

### `compress_drive.py`
| Argument | Default | Description |
| --- | --- | --- |
| `input` | required | source folder, searched with `--pattern` |
| `output` | required | archive root; compressed files and run records are written under it |
| `--output_studyname` | required | study-name prefix for archive folders (e.g. `LS`), independent of whatever prefix the source files carry |
| `--pattern` | `**/LS*/*.mp4` | glob selecting which source files are in scope |
| `--motion_detection` | off | analyse each raw clip for motion and compress motionless clips much more strongly; also saves per-frame motion values. Off: every clip is encoded at `--taskcam_crf`. Never applied to already-compressed sources |
| `--motion_percentile` | `99.9` | with motion detection: percentile of the per-frame motion values used as a clip's motion score |
| `--motion_threshold` | `0` | with motion detection: a clip whose score is at or above this counts as having motion. 0 treats every clip as motion while still recording the motion values; we use `0.001` for our rats, calibrated on our own raw video |
| `--n_threads` | `4` | threads given to ffmpeg |
| `--taskcam_crf` | `25` | ffmpeg quality (CRF) for task-chamber views with motion, and for every clip when motion detection is off; lower is better quality and larger files |
| `--compress_spd` | `veryfast` | ffmpeg preset; slower presets give smaller files for the same quality |
| `--recompress` | off | re-encode source files that are already compressed instead of copying them as-is (a second lossy generation — for when the raw originals are gone and the first compression was too weak) |
| `--overwrite_raw` | off | replace a raw (uncompressed) video found at the destination with the processed source |
| `--overwrite_compressed` | off | replace a compressed video found at the destination with a fresh processing of the source |

### `confirm_and_delete.py`
| Argument | Default | Description |
| --- | --- | --- |
| `source` | required | folder holding the originals you are considering deleting |
| `destination` | required | archive root (the folder you gave `compress_drive.py` as `output`) |
| `--output_studyname` | required | study-name prefix used in the archive |
| `--pattern` | `**/LS*/*.mp4` | glob selecting which source files are in scope |
| `--min_age_hours` | `24` | an archived copy modified more recently than this is not yet deletable — a proxy for "a backup has run since it was written"; backups themselves are not checked |
| `--decode` / `--no-decode` | on with `--delete`, else off | fully decode every archived copy with ffmpeg |
| `--delete` | off | after the checks, delete the verified originals (asks you to type `DELETE`) |
| `--delete_partial` | off | with `--delete`: proceed even if some files could not be verified (they are left in place). Without it, any unverified file blocks all deletion |

### About motion detection
With `--motion_detection`, the tool samples every tenth frame of a clip at reduced resolution, subtracts a running background, and records the fraction of pixels that changed. The clip's motion score is a high percentile of those values; if it reaches `--motion_threshold`, the clip is encoded at a visually lossless setting, otherwise at a very strong compression that is adequate for an empty or sleeping-animal view. Our threshold was chosen empirically so that any clip in which an awake rat is present, however briefly, is kept at full quality.

The threshold and percentile are specific to our cameras, lighting and animals; another setup will need its own calibration, which is why the tool's default is to compress everything at full quality and record the motion values (`motion_timeseries.csv`) for later analysis rather than act on them. Already-compressed sources are never motion-analysed: compression artifacts register as motion and would defeat the purpose.

## Technical Details
Information below here is not necessary to use the tools, but may be useful when something unexpected turns up or when reconstructing how an archived clip was made.

### Where metadata is saved
Every run — compression or verification — creates its own folder under the archive root:

```
<archive root>/videoproc_run_metadata/<run_id>/
```

`run_id` is `videoproc_<date>_<time>_<random>` for `compress_drive.py` and `confirm_<date>_<time>_<random>` for `confirm_and_delete.py`. The folder is created at the start, so even an interrupted run leaves a record.

| File | Written by | Contents |
| --- | --- | --- |
| `config.json` | both | every argument the run was given; `code_version` (the git commit of the code, `+dirty` if it had uncommitted edits); for compression runs also `encoding_policy` (codec, pixel format, preset, view lists, CRF per branch, no-motion GOP) and `motion_detection` (enabled, percentile, threshold, detector parameters) |
| `manifest.csv` | both | per (subject, view) stream: date range covered and file count seen in the source scan |
| `log.csv` | both | one row per file considered: `input_path`, `output_path`, `start_time`, `status`, `action_item`, `skipped_reason`, `error`, then the compression fields (`motion_perc`, `found_motion`, `motion_detection_time`, `fract_frames_exceeding`, `compression_ratio`, `compression_success`, `compression_time`, `valid_output`); verification runs add `source_codec`, `destination_codec`, `destination_mtime`, `age_hours`, `size_ratio`, `decode_ok`, `deletable` |
| `action_items.csv` | both | the subset of `log.csv` rows flagged for human review (header only if none) |
| `terminal.log` | both | a copy of the terminal output including the end-of-run summary (messages printed directly by OpenCV or ffmpeg are not captured) |
| `motion_timeseries.csv` | compression, only with `--motion_detection` | one row per compressed clip: `clip_filename`, `motion_values` (space-separated, one value per sampled frame, 4 significant digits) |
| `deletion_log.csv` | verification, only when files were deleted | one row per deleted original: `input_path`, `output_path`, `input_size_bytes`, `deleted_at` |

In addition `<archive root>/videoproc_run_metadata/index.csv` gains one line per run (run id, subjects, date range, stream and file counts). Appends to it are locked so runs from several computers can share one archive.

The footprint is about 9 KB per compressed clip (of which ~8 KB is the motion timeseries) and about 0.6 KB per verified clip — well under 0.1 % of the video.

### What happens to each file
For every file matching `--pattern`, `compress_drive.py` parses the filename, computes the destination path, probes both files (codec and frame count), and decides:

| Source | Destination | Result | Status | Flagged |
| --- | --- | --- | --- | --- |
| cannot be opened | nothing there | nothing written | `invalid_source` | no |
| cannot be opened | cannot be opened | nothing written | `invalid_source` | no |
| cannot be opened | valid, compressed | nothing written | `invalid_source` | no |
| cannot be opened | valid, **raw** | nothing written | `invalid_source` | **yes** |
| valid | nothing there | compress or copy | — | — |
| valid | cannot be opened | compress or copy; the broken file is replaced | — | — |
| valid | valid, frame count **differs** | nothing written | `collision` | **yes** |
| valid | valid, compressed, frame count matches | skip unless `--overwrite_compressed` | `already_done` | no |
| valid | valid, raw, frame count matches | skip unless `--overwrite_raw` | `raw_at_destination` | **yes** |

A valid source that is itself already compressed is copied byte-for-byte unless `--recompress` is given. Otherwise it is encoded and then verified: the output must exist, be non-empty, and have the same frame count as the source — else `output_invalid`, flagged. Unparseable filenames give `unparseable` (flagged); `.mp4` files outside the pattern give `pattern_mismatch` rows (flagged; listed individually only when there are ten or fewer); unexpected exceptions give `error` (flagged); files never reached because connectivity was lost give `not_attempted` (flagged).

`confirm_and_delete.py` applies the same table in report-only form and adds `not_at_destination`, `destination_invalid`, `too_recent` and `decode_failed`, all flagged. A file is deletable only if its status is `already_done` after the age gate and the decode check.

### Compression settings in force
Outputs are H.264 (`libx264`, `yuv420p`). With motion detection off, or for an already-compressed source, every clip is encoded at `--taskcam_crf`. With motion detection on: clips with motion from the task-chamber views (`lid`, `face`) use `--taskcam_crf`; clips with motion from the cage views (`buddy`, `home`) use CRF 30; clips with motion from any other view name use `--taskcam_crf` and produce a warning, since an unknown view name usually means a misnamed file; clips without motion use CRF 40 with a 1800-frame keyframe interval. The view names are currently fixed in the code; the complete table in force is written to each run's `config.json`.

### Legacy filenames and `custom_filename_parser.py`
The tools recognize one filename shape, `<subjectID>_<view>_<YYYYMMDD>_<HH-MM-SS>.mp4`. For archives with older conventions, copy `videoproc/custom_filename_parser_example.py` to `videoproc/custom_filename_parser.py` and implement `parse(stem)`, which receives the filename without extension and returns `(subjectID, view, YYYYMMDD, HH-MM-SS)` or `None`. The tools call it for any name the standard rule does not recognize. The file is excluded from version control because it describes your data, not the tool.

### Timing and capacity
On an 8-core Apple-silicon Mac with 10-minute 640×480 clips: compression about 12–15 s per clip plus about 11 s of motion detection when enabled; verification probe about one minute per thousand clips; decode about 1–3 s per clip. Raw clips of 200–770 MB typically compress to 1–60 MB depending on view and motion, an aggregate ratio of roughly 25–30 to one. The source and destination may both be on a network volume; a dropped mount pauses the run (fast retries for a minute, then every ten minutes, for up to ten hours) rather than failing it.

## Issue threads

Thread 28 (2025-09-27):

consider using NAS instead of external drives

preinagel, 2025-09-27:
Is there any good reason we need to use external drives at all?

What if all the macs mounted one of our servers as an external drive through the internal network, and transferred the temporary videos directly to an INCOMING folder there; and then another dedicated machine anywhere in the lab (such as the upstairs mac) watches for new videos to appear, compresses them and transfers them to their permanent folders?  (For now the originals could be manually deleted after someone manually verifies all is good, but eventually that could be automatic as well).

I keep the ratrixcam macs in airplane mode to minimize the chance of any processes launching that we didn't initiate (such as automatic updates). But if we hard-wired them to our private internal network router, perhaps that's not risky.

If the private network goes down, temporary videos will pile up on the macs' internal HDs until it comes back online; we should check how much empty space the macs have on their drives and calculate how long they could go before they ran out of space.

The private network goes down semi-often because the computer hosting the internal network periodically updates and resets its network security settings; but maybe we could control when that happens by rebooting or updating it ourselves once a week.

BETTER YET - once we are satisfied with code that checks for completeness of a compression step and automatically deletes the uncompressed original we can do it this way:

- Put an NAS on the internal network to receive the uncompressed files.
- Put a mac on the internal network running a script to watch for new files in its INCOMING folder and compress them to an OUTGOING folder.
- an independent script that watches for new compressed files and transfers them to the main server, deleting the uncompressed file as soon as the remote server copy is confirmed
- an independent script that waits until compressed files have been on the main server for [sufficient time for a server backup], and then deletes the compressed files
- If we lose network connectivity, the compression mac can keep receiving uncompressed videos and  keep compressing them until the NAS fills up.
- Then the macs can keep recording until their HDs fill up.
- So we'd want the NAS to be large enough to hold 1 week uncompressed video + the compressed copies, with some overhead to spare.

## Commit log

2025-06-17 switch to multiprocessing
2025-06-18 attempt to restart camera if read a bad frame
2025-06-24 switched to individual camera configuration
2025-06-25 add more space for update config button
2025-06-27 longer pause between launching cameras, improved timestamp overlays
2025-06-27 Update ratrix_multicam.py
    added checking for recent camera launch, and sleeping before another one attempts to launch
2025-07-11 add informative feedback
    messages to console useful for debugging camera launching order and issues
2025-07-15 frame timing
    minor changes to test or improve timestamps, add frame# to overlay
2025-07-16 add on-the-fly transcoding
    Instead of copying video files from temp to out directory, call ffmpeg to transcode them (with videotoolbox, not on CPU) to out directory.
    This version works repeatably on a MacMini2 test station with 8 cameras, but it is fragile: depends crucially on timeouts to handle race conditions of unclear origin.
2025-07-17 turn off transcoding; text scaling
    Until transcoding is more efficient and robust, hardwire code to use simple copy command instead
    improved scaling and positioning of overlaid text relative to camera resolution selected
2025-08-14 3D Print files for camera cases
    [ratrixCamCameraCaseBack.stl, ratrixCamCameraCaseFront.stl]
2026-10-08 videoproc: compact motion_timeseries.csv (one row per clip, 4 significant digits)
    The per-sample long format repeated the clip filename on every row and wrote full-precision
    floats, ~84 KB per clip; one row per clip with space-separated values is ~8 KB.
2026-10-08 docs: split user manual into camera and videoproc manuals
    UserManual.md becomes CameraUserManual.md (content unchanged apart from pointing the
    compression paragraph at the new manual); VideoProcUserManual.md documents compress_drive
    and confirm_and_delete in the same style, including where run metadata is saved.
2026-10-09 Automate run metadata: ratrixcam terminal log, config copy and shutdown collection; videoproc carries it (#34)
    ratrixcam: everything printed by the run (including spawned camera processes) is teed to a log
    file in the temp folder from the moment the config loads, with the code version on the first
    line; Start Recording copies the config in use to <save_path>/ratrixcam_run_metadata/<run_id>/
    with a notes template; after the cameras have shut down, the stills, loose temp files and the
    log are gathered into that folder (non-empty per-camera temp folders are left alone and named).
    Camera capture, transfer and shutdown logic are untouched.
    videoproc: compress_drive transfers ratrixcam_run_metada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
2026-10-13 videoproc: motion review of no-motion clips
    - peak-motion still saved per no-motion clip in <run>/no_motion_stills/
    - no-motion clips with any sampled frame at --motion_threshold listed in
    motion_review.csv and counted in the run summary; time series kept only
    for motion clips and flagged clips (--no-motion_review: previous behaviour)
    - log.csv: motion_max, n_frames_over_threshold, motion_review_flag
    - manual: warning on CRF levels vs later motion analysis; threshold must be
    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
2026-10-13 ratrixcam: shutdown collection moves stills and cleans the temp folder (#34)
    - status stills moved, not copied, into <run>/stills/; emptied stills and
    temp folders removed
    - collection report printed before the terminal log is closed and moved,
    so the log records it
2026-10-14 rename ratrix_* modules to ratrixcam_*
    ratrix_cam_server -> ratrixcam_server, ratrix_multicam -> ratrixcam_multi,
    ratrix_utils -> ratrixcam_utils, ratrix_run_metadata -> ratrixcam_run_metadata,
    ratrix_naming -> ratrixcam_naming; imports, tests and manual updated.
    Printed process names and window titles now say ratrixcam.
2026-10-19 config: subject_prefix, default_crf, per-camera subjID/view/position/crf
    rack_name, blank_image, stills_path and per-camera name/row/col removed
    camera name built from subject_prefix + subjID + _ + view
    stills folder is temp_path/status; blank image is code-relative
    Tkinter config editor replaced by a Start button; duplicate camera checks
    parsers removed from ratrixcam_naming (videoproc on dev broken until the manifest step)
    example config.json in the new format
2026-10-21 ratrixcam: per-clip manifest
    each camera appends one row per closed clip to <temp_path>/<camera name>_manifest.csv
    (path, subjID, view, clip_start, row_written, crf); written in close_writer before the transfer starts;
    three attempts then a warning, recording never blocks on it
    shutdown collection moves the manifests to <save_path>/manifests_<run_id>/
2026-10-21 added handling in case rows failed to append to manifest
2026-10-21 basedpyright errors resolved except the documented frame check in the camera core
2026-10-22 manifests live inside the run's metadata folder, on the camera side and in the wrapper
2026-10-28 independent review fixes: a refused launch leaves no log in temp; manifest rows written once with no sleep on the frame loop; day folders created one level only; clips flushed to the drive before the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
2026-10-28 launch probes that the save drive folder is writable
2026-10-31 pyright: frame initialised before the read loop; the checker's last five errors gone
2026-11-02 gui worktree: sample temp folder for the viewer, clips ignored
2026-11-03 gui: iteration 2: accounting table below the cameras, viewer-side drive warning stages, crash vs clean-stop banner, run-ended screen
2026-11-03 gui: second sample temp folder (7 cameras), nested gitignore keeping stills and dropping clips, run simulator
2026-11-03 gui: no-space banners say cameras are no longer being recorded, no temp cache line once the temp drive is full too
2026-11-03 gui: camera config editor draft: form of drop-down menus fed by a per-machine legal-values file, add-new dialog with checks, duplicate camera and position rules, save through a separate server that v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
2026-11-03 gui: config editor round 2: one resolution field, advanced defaults at the bottom with presets, per-camera override lists start empty, name length limits, absolute paths, file key order run/cameras/d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
2026-11-03 gui: config editor: (default) shown in the legal-values panel for per-camera lists; menu re-filled after a choice so the not-in-list flag clears
2026-11-04 gui: notes trimmed to the current state
